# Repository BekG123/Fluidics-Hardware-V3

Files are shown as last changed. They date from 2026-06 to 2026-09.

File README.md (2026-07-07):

Cephla

# Fluidics Controller PCB (V3)

A KiCad hardware design for the fluidics controller used on Cephla/Squid
microscopy systems. It drives the pumps, valves, and sensors that move and
monitor liquid through the instrument, all coordinated by an on-board
Teensy 4.1 microcontroller.

## What it does

The board is the single point of electrical control for the instrument's
liquid path. The Teensy firmware talks to each subsystem over the bus noted
below and exposes a serial interface to the host software.

## Subsystems

| Subsystem | Qty | Interface | Notes |
|---|---|---|---|
| Syringe pump | 1 | RS-232 (`J3`, DB15) | Primary fluid actuation |
| Solenoid valves | up to 7 | GPIO → `U1` TPL7407 → `J5` screw terminal | Low-side driver + per-channel status LEDs |
| Selector valves (IDEX) | 6 | Isolated I²C (5 V) | Addresses set on each valve module |
| Flow sensors | 3 | I²C @ 0x08 | One per I²C port (`J15`/`J17`/`J20`) — fixed address forces separate buses |
| Bubble sensors | 2 | Digital, level-shifted (`J2`/`J4`) | Not I²C |

Isolation and bus conditioning are handled by ADuM1250 / ISO7021 isolators,
a PCA9615 differential-I²C link, and UART/logic level shifters.

## Board specs

- **MCU:** Teensy 4.1 (footprint `U2`, on-board)
- **Stack-up:** 4-layer — `F.Cu` / `In1.Cu` (GND) / `In2.Cu` (+24 V & +5 V planes) / `B.Cu`
- **Power:** +24 V input; Pololu DC-DC regulators for +5 V; on-board LDO (`U3`) for +3.3 V
- **Mounting:** 4 corner plated holes (`H1`–`H4`), chassis GND

## Fabrication

The ready-to-order package lives in `fabrication/v3/`

## Attribution

Derived from `Fluidics-Hardware-V2` by Kevin Marx. V3 modifications by
Bekhruz Malikov (<bekhruz.malikov@cephla.com>). Built with KiCad 10.

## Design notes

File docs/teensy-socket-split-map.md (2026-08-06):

# Teensy socket split (Route B) — pin/net map

Generated from `fluidics-v3/fluidics-v2.kicad_pcb`. U2 origin **(178.23, 51.33)**, rotation 0.

## Parts

| Part | Covers | Footprint | PCB position | PCB rotation |
|---|---|---|---|---|
| **J6** (left socket) | old U2 pins **1–24** | `teensy4.1:PinSocket_1x24_P2.54mm_Vertical_SMD_DualLand` | 170.61, 51.33 | 0° |
| **J7** (right socket) | old U2 pins **25–48** | same footprint | 185.85, 51.33 | 180° |

Both sockets are the same part (Harwin M20-786 series, 1×24 SMT). J7 is J6 rotated 180°, which is why J7 pin *n* lands on old U2 pin *n+24*. Schematic rotation is irrelevant — only the **PCB** rotation above matters.

> Note: auto-annotation reused the designators **J6/J7**, which belonged to the 1×02 terminal blocks removed in commit `5ce1d61`. Renaming them to J26/J27 avoids confusion when comparing against older fab packages, but is optional.

## How to connect (summary)

| Method | Count | Pins (U2 numbering) |
|---|---:|---|
| Label | 34 | 4, 5, 6, 7, 8, 9, 10, 11, 12, 13, 14, 16, 17, 24, 25, 26, 27, 28, 29, 30, 31, 32, 33, 35, 36, 37, 38, 39, 40, 41, 42, 43, 44, 45 |
| **GND power symbol** | 3 | 1, 34, 47 |
| **No-connect flag** | 4 | 2, 3, 15, 46 |
| **Label both ends** | 7 | 18, 19, 20, 21, 22, 23, 48 |

Label text **never includes the leading `/`** — that is the sheet path, not part of the name. `~{...}` is overbar markup and must be typed exactly as shown.

## Full map

| U2 pin | Teensy function | Current net | Socket | Socket pin | Label text to place | Method |
|---:|---|---|---|---:|---|---|
| 1 | GND_1 | `GND` | J6 | 1 | `GND` | **GND power symbol** |
| 2 | 0_RX1_CRX2_CS1_2 | *(auto)* | J6 | 2 | — | **No-connect flag** |
| 3 | 1_TX1_CTX2_MISO1_3 | *(auto)* | J6 | 3 | — | **No-connect flag** |
| 4 | 2_OUT2_4 | `/VALVES_~{RST}` | J6 | 4 | `VALVES_~{RST}` | Label |
| 5 | 3_LRCLK2_5 | `/VALVES_PWM` | J6 | 5 | `VALVES_PWM` | Label |
| 6 | 4_BCLK2_6 | `/GPIO_9` | J6 | 6 | `GPIO_9` | Label |
| 7 | 5_IN2_7 | `/GPIO_8` | J6 | 7 | `GPIO_8` | Label |
| 8 | 6_OUT1D_8 | `/~{INVALID}_SYRPUMP` | J6 | 8 | `~{INVALID}_SYRPUMP` | Label |
| 9 | 7_RX2_OUT1A_9 | `/UART_TX_SYRPUMP` | J6 | 9 | `UART_TX_SYRPUMP` | Label |
| 10 | 8_TX2_IN1_10 | `/UART_RX_SYRPUMP` | J6 | 10 | `UART_RX_SYRPUMP` | Label |
| 11 | 9_OUT1C_11 | `/SPI_~{CS}_PRESS` | J6 | 11 | `SPI_~{CS}_PRESS` | Label |
| 12 | 10_CS_MQSR_12 | `/SPI_~{CS}_VALVES` | J6 | 12 | `SPI_~{CS}_VALVES` | Label |
| 13 | 11_MOSI_CTX1_13 | `/SPI_MOSI` | J6 | 13 | `SPI_MOSI` | Label |
| 14 | 12_MISO_MQSL_14 | `/SPI_MISO` | J6 | 14 | `SPI_MISO` | Label |
| 15 | 3V3_15 | *(auto)* | J6 | 15 | — | **No-connect flag** |
| 16 | 24_A10_TX6_SCL2_16 | `/SCL2` | J6 | 16 | `SCL2` | Label |
| 17 | 25_A11_RX6_SDA2_17 | `/SDA2` | J6 | 17 | `SDA2` | Label |
| 18 | 26_A12_MOSI1_18 | `/Bubble Sensors/2B 3.3V` | J6 | 18 | `BUB_2B` | **Label both ends** |
| 19 | 27_A13_SCK1_19 | `/Bubble Sensors/2A 3.3V` | J6 | 19 | `BUB_2A` | **Label both ends** |
| 20 | 28_RX7_20 | `/Bubble Sensors/1B 3.3V` | J6 | 20 | `BUB_1B` | **Label both ends** |
| 21 | 29_TX7_21 | `/Bubble Sensors/1A 3.3V` | J6 | 21 | `BUB_1A` | **Label both ends** |
| 22 | 30_CRX3_22 | `/Bubble Sensors/Calib 2 3.3V` | J6 | 22 | `BUB_CALIB2` | **Label both ends** |
| 23 | 31_CTX3_23 | `/Bubble Sensors/Calib 1 3.3V` | J6 | 23 | `BUB_CALIB1` | **Label both ends** |
| 24 | 32_OUT1B_24 | `/PG-12V` | J6 | 24 | `PG-12V` | Label |
| 25 | 33_MCLK2_25 | `/PG-5V` | J7 | 1 | `PG-5V` | Label |
| 26 | 34_RX8_26 | `/~{CS}3` | J7 | 2 | `~{CS}3` | Label |
| 27 | 35_TX8_27 | `/~{CS}2` | J7 | 3 | `~{CS}2` | Label |
| 28 | 36_CS_28 | `/~{CS}1` | J7 | 4 | `~{CS}1` | Label |
| 29 | 37_CS_29 | `/~{CS}0` | J7 | 5 | `~{CS}0` | Label |
| 30 | 38_CS1_IN1_30 | `/GPIO_7` | J7 | 6 | `GPIO_7` | Label |
| 31 | 39_MISO1_OUT1A_31 | `/GPIO_6` | J7 | 7 | `GPIO_6` | Label |
| 32 | 40_A16_32 | `/GPIO_5` | J7 | 8 | `GPIO_5` | Label |
| 33 | 41_A17_33 | `/POT_ANALOG` | J7 | 9 | `POT_ANALOG` | Label |
| 34 | GND_34 | `GND` | J7 | 10 | `GND` | **GND power symbol** |
| 35 | 13_SCK_LED_35 | `/SPI_SCK` | J7 | 11 | `SPI_SCK` | Label |
| 36 | 14_A0_TX3_SPDIF_OUT_36 | `/UART_RX_DISCPUMP` | J7 | 12 | `UART_RX_DISCPUMP` | Label |
| 37 | 15_A1_RX3_SPDIF_IN_37 | `/UART_TX_DISCPUMP` | J7 | 13 | `UART_TX_DISCPUMP` | Label |
| 38 | 16_A2_RX4_SCL1_38 | `/SCL1` | J7 | 14 | `SCL1` | Label |
| 39 | 17_A3_TX4_SDA1_39 | `/SDA1` | J7 | 15 | `SDA1` | Label |
| 40 | 18_A4_SDA_40 | `/SCL` | J7 | 16 | `SCL` | Label |
| 41 | 19_A5_SCL_41 | `/SDA` | J7 | 17 | `SDA` | Label |
| 42 | 20_A6_TX5_LRCLK1_42 | `/GPIO_4` | J7 | 18 | `GPIO_4` | Label |
| 43 | 21_A7_RX5_BCLK1_43 | `/GPIO_3` | J7 | 19 | `GPIO_3` | Label |
| 44 | 22_A8_CTX1_44 | `/GPIO_2` | J7 | 20 | `GPIO_2` | Label |
| 45 | 23_A9_CRX1_MCLK1_45 | `/GPIO_1` | J7 | 21 | `GPIO_1` | Label |
| 46 | 3V3_46 | *(auto)* | J7 | 22 | — | **No-connect flag** |
| 47 | GND_47 | `GND` | J7 | 23 | `GND` | **GND power symbol** |
| 48 | VIN_48 | `Net-(D21-K)` | J7 | 24 | `VIN` | **Label both ends** |

## The 7 pins that need care

- **U2.18** (26_A12_MOSI1_18) — `/Bubble Sensors/2B 3.3V`: named inside the *Bubble Sensors* subsheet; label the root-sheet wire too. Put `BUB_2B` on the existing U2 pin wire **and** on J6.18. This renames the net to `/BUB_2B` in the PCB (cosmetic).
- **U2.19** (27_A13_SCK1_19) — `/Bubble Sensors/2A 3.3V`: named inside the *Bubble Sensors* subsheet; label the root-sheet wire too. Put `BUB_2A` on the existing U2 pin wire **and** on J6.19. This renames the net to `/BUB_2A` in the PCB (cosmetic).
- **U2.20** (28_RX7_20) — `/Bubble Sensors/1B 3.3V`: named inside the *Bubble Sensors* subsheet; label the root-sheet wire too. Put `BUB_1B` on the existing U2 pin wire **and** on J6.20. This renames the net to `/BUB_1B` in the PCB (cosmetic).
- **U2.21** (29_TX7_21) — `/Bubble Sensors/1A 3.3V`: named inside the *Bubble Sensors* subsheet; label the root-sheet wire too. Put `BUB_1A` on the existing U2 pin wire **and** on J6.21. This renames the net to `/BUB_1A` in the PCB (cosmetic).
- **U2.22** (30_CRX3_22) — `/Bubble Sensors/Calib 2 3.3V`: named inside the *Bubble Sensors* subsheet; label the root-sheet wire too. Put `BUB_CALIB2` on the existing U2 pin wire **and** on J6.22. This renames the net to `/BUB_CALIB2` in the PCB (cosmetic).
- **U2.23** (31_CTX3_23) — `/Bubble Sensors/Calib 1 3.3V`: named inside the *Bubble Sensors* subsheet; label the root-sheet wire too. Put `BUB_CALIB1` on the existing U2 pin wire **and** on J6.23. This renames the net to `/BUB_CALIB1` in the PCB (cosmetic).
- **U2.48** (VIN_48) — `Net-(D21-K)`: net is unnamed today; label U2.48 *and* the socket pin. Put `VIN` on the existing U2 pin wire **and** on J7.24. This renames the net to `/VIN` in the PCB (cosmetic).

## Verification

After Update PCB and a zone refill, DRC must match the current baseline: **6 unconnected** (5 intentional GPIO_8/9 + SPI no-connects, 1 pre-existing +5V stub gap near U13/U4), 0 shorts / clearance / isolated copper / starved thermals. A higher count means a mismapped pin.

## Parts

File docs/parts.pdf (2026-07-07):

JLCPCB PCBA Viewer | https://cart.jlcpcb.com/smt-order/?pcbFileNo=f7d9450...

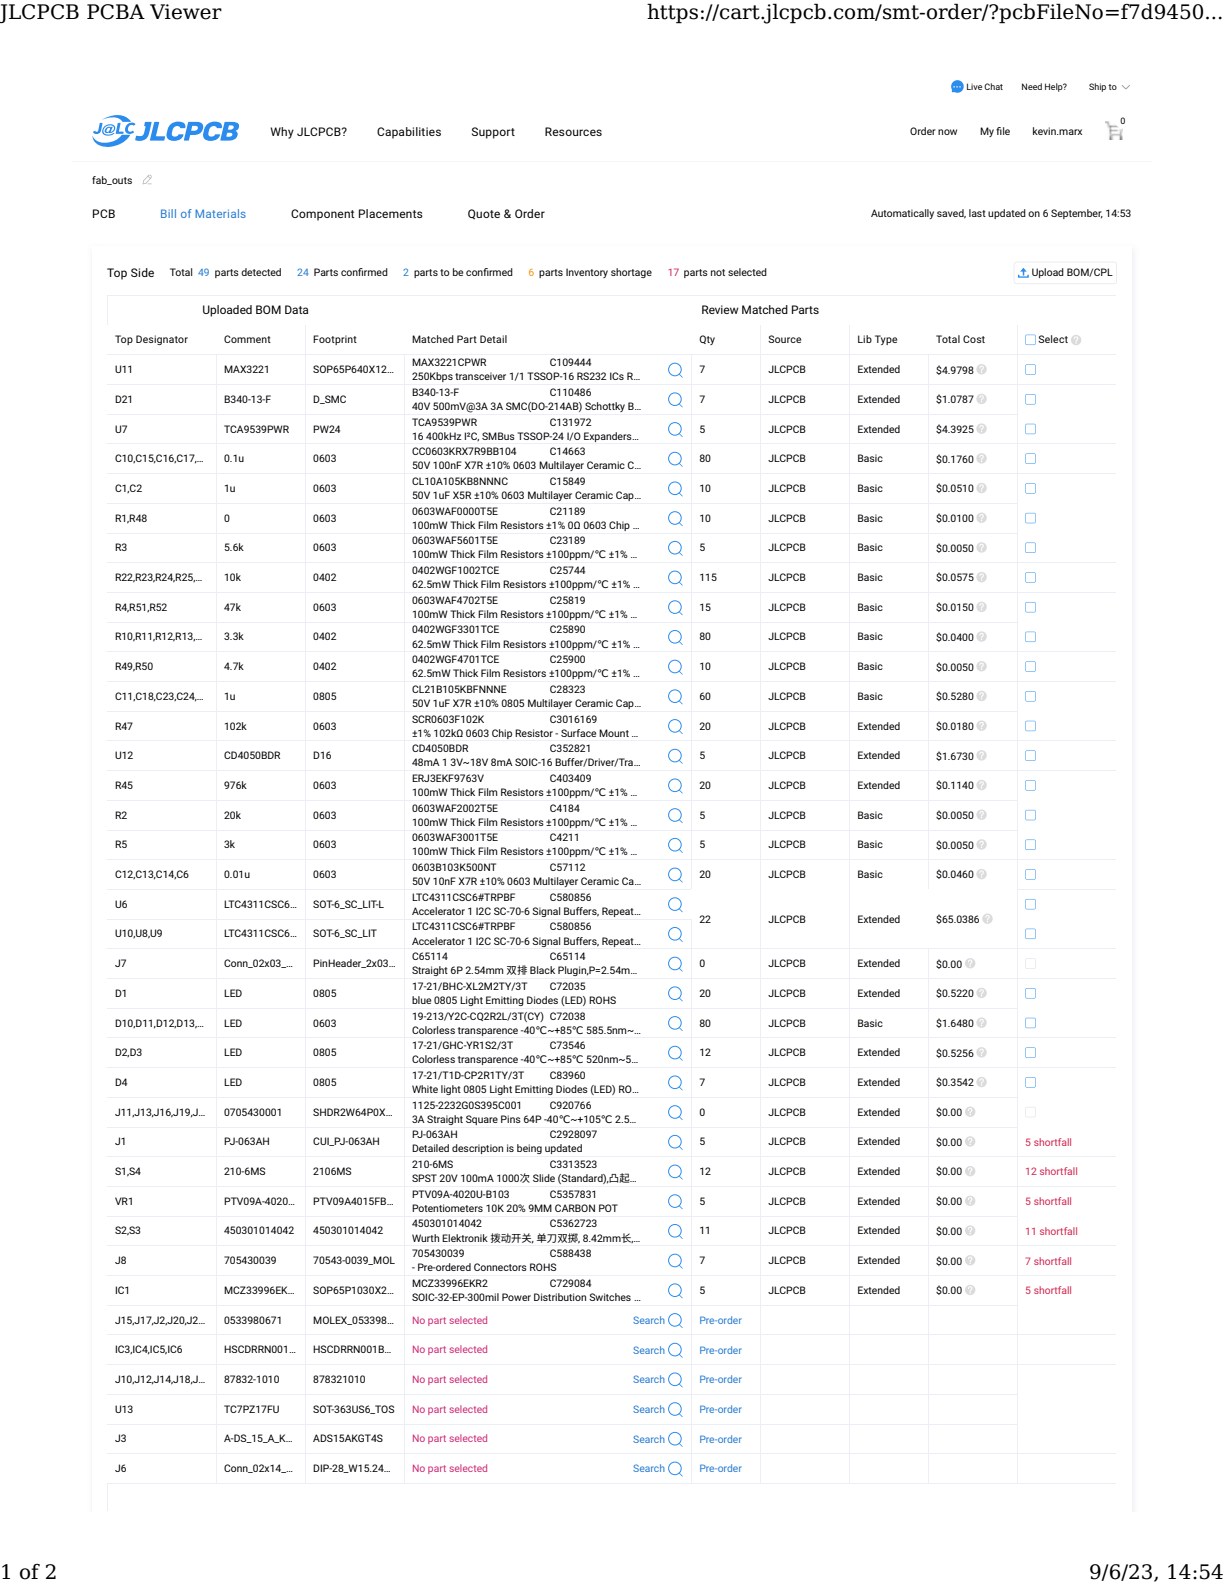
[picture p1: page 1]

Automatically saved, last updated on 6 September, 14:53

Uploaded BOM Data | Review Matched Parts

Top Designator | Comment | Footprint | Matched Part Detail | Qty | Source | Lib Type | Total Cost | Select

U11 | MAX3221 | SOP65P640X12… | MAX3221CPWR C109444 250Kbps transceiver 1/1 TSSOP-16 RS232 ICs R… | 7 | JLCPCB | Extended | $4.9798

D21 | B340-13-F | D_SMC | B340-13-F C110486 40V 500mV@3A 3A SMC(DO-214AB) Schottky B… | 7 | JLCPCB | Extended | $1.0787

U7 | TCA9539PWR | PW24 | TCA9539PWR C131972 16 400kHz I²C, SMBus TSSOP-24 I/O Expanders… | 5 | JLCPCB | Extended | $4.3925

C10,C15,C16,C17,… | 0.1u | 0603 | CC0603KRX7R9BB104 C14663 50V 100nF X7R ±10% 0603 Multilayer Ceramic C… | 80 | JLCPCB | Basic | $0.1760

C1,C2 | 1u | 0603 | CL10A105KB8NNNC C15849 50V 1uF X5R ±10% 0603 Multilayer Ceramic Cap… | 10 | JLCPCB | Basic | $0.0510

R1,R48 | 0 | 0603 | 0603WAF0000T5E C21189 100mW Thick Film Resistors ±1% 0Ω 0603 Chip … | 10 | JLCPCB | Basic | $0.0100

R3 | 5.6k | 0603 | 0603WAF5601T5E C23189 100mW Thick Film Resistors ±100ppm/℃ ±1% … | 5 | JLCPCB | Basic | $0.0050

R22,R23,R24,R25,… | 10k | 0402 | 0402WGF1002TCE C25744 62.5mW Thick Film Resistors ±100ppm/℃ ±1% … | 115 | JLCPCB | Basic | $0.0575

R4,R51,R52 | 47k | 0603 | 0603WAF4702T5E C25819 100mW Thick Film Resistors ±100ppm/℃ ±1% … | 15 | JLCPCB | Basic | $0.0150

R10,R11,R12,R13,… | 3.3k | 0402 | 0402WGF3301TCE C25890 62.5mW Thick Film Resistors ±100ppm/℃ ±1% … | 80 | JLCPCB | Basic | $0.0400

R49,R50 | 4.7k | 0402 | 0402WGF4701TCE C25900 62.5mW Thick Film Resistors ±100ppm/℃ ±1% … | 10 | JLCPCB | Basic | $0.0050

C11,C18,C23,C24,… | 1u | 0805 | CL21B105KBFNNNE C28323 50V 1uF X7R ±10% 0805 Multilayer Ceramic Cap… | 60 | JLCPCB | Basic | $0.5280

R47 | 102k | 0603 | SCR0603F102K C3016169 ±1% 102kΩ 0603 Chip Resistor - Surface Mount … | 20 | JLCPCB | Extended | $0.0180

U12 | CD4050BDR | D16 | CD4050BDR C352821 48mA 1 3V~18V 8mA SOIC-16 Buffer/Driver/Tra… | 5 | JLCPCB | Extended | $1.6730

R45 | 976k | 0603 | ERJ3EKF9763V C403409 100mW Thick Film Resistors ±100ppm/℃ ±1% … | 20 | JLCPCB | Extended | $0.1140

R2 | 20k | 0603 | 0603WAF2002T5E C4184 100mW Thick Film Resistors ±100ppm/℃ ±1% … | 5 | JLCPCB | Basic | $0.0050

R5 | 3k | 0603 | 0603WAF3001T5E C4211 100mW Thick Film Resistors ±100ppm/℃ ±1% … | 5 | JLCPCB | Basic | $0.0050

C12,C13,C14,C6 | 0.01u | 0603 | 0603B103K500NT C57112 50V 10nF X7R ±10% 0603 Multilayer Ceramic Ca… | 20 | JLCPCB | Basic | $0.0460

U6 | LTC4311CSC6… | SOT-6_SC_LIT-L | LTC4311CSC6#TRPBF C580856 Accelerator 1 I2C SC-70-6 Signal Buffers, Repeat… | 22 | JLCPCB | Extended | $65.0386

U10,U8,U9 | LTC4311CSC6… | SOT-6_SC_LIT | LTC4311CSC6#TRPBF C580856 Accelerator 1 I2C SC-70-6 Signal Buffers, Repeat…

J7 | Conn_02x03_… | PinHeader_2x03… | C65114 C65114 Straight 6P 2.54mm 双排 Black Plugin,P=2.54m… | 0 | JLCPCB | Extended | $0.00

D1 | LED | 0805 | 17-21/BHC-XL2M2TY/3T C72035 blue 0805 Light Emitting Diodes (LED) ROHS | 20 | JLCPCB | Extended | $0.5220

D10,D11,D12,D13,… | LED | 0603 | 19-213/Y2C-CQ2R2L/3T(CY) C72038 Colorless transparence -40℃~+85℃ 585.5nm~… | 80 | JLCPCB | Basic | $1.6480

D2,D3 | LED | 0805 | 17-21/GHC-YR1S2/3T C73546 Colorless transparence -40℃~+85℃ 520nm~5… | 12 | JLCPCB | Extended | $0.5256

D4 | LED | 0805 | 17-21/T1D-CP2R1TY/3T C83960 White light 0805 Light Emitting Diodes (LED) RO… | 7 | JLCPCB | Extended | $0.3542

J11,J13,J16,J19,J… | 0705430001 | SHDR2W64P0X… | 1125-2232G0S395C001 C920766 3A Straight Square Pins 64P -40℃~+105℃ 2.5… | 0 | JLCPCB | Extended | $0.00

J1 | PJ-063AH | CUI_PJ-063AH | PJ-063AH C2928097 Detailed description is being updated | 5 | JLCPCB | Extended | $0.00 | 5 shortfall

S1,S4 | 210-6MS | 2106MS | 210-6MS C3313523 SPST 20V 100mA 1000次 Slide (Standard),凸起… | 12 | JLCPCB | Extended | $0.00 | 12 shortfall

VR1 | PTV09A-4020… | PTV09A4015FB… | PTV09A-4020U-B103 C5357831 Potentiometers 10K 20% 9MM CARBON POT | 5 | JLCPCB | Extended | $0.00 | 5 shortfall

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

JLCPCB PCBA Viewer | https://cart.jlcpcb.com/smt-order/?pcbFileNo=f7d9450...

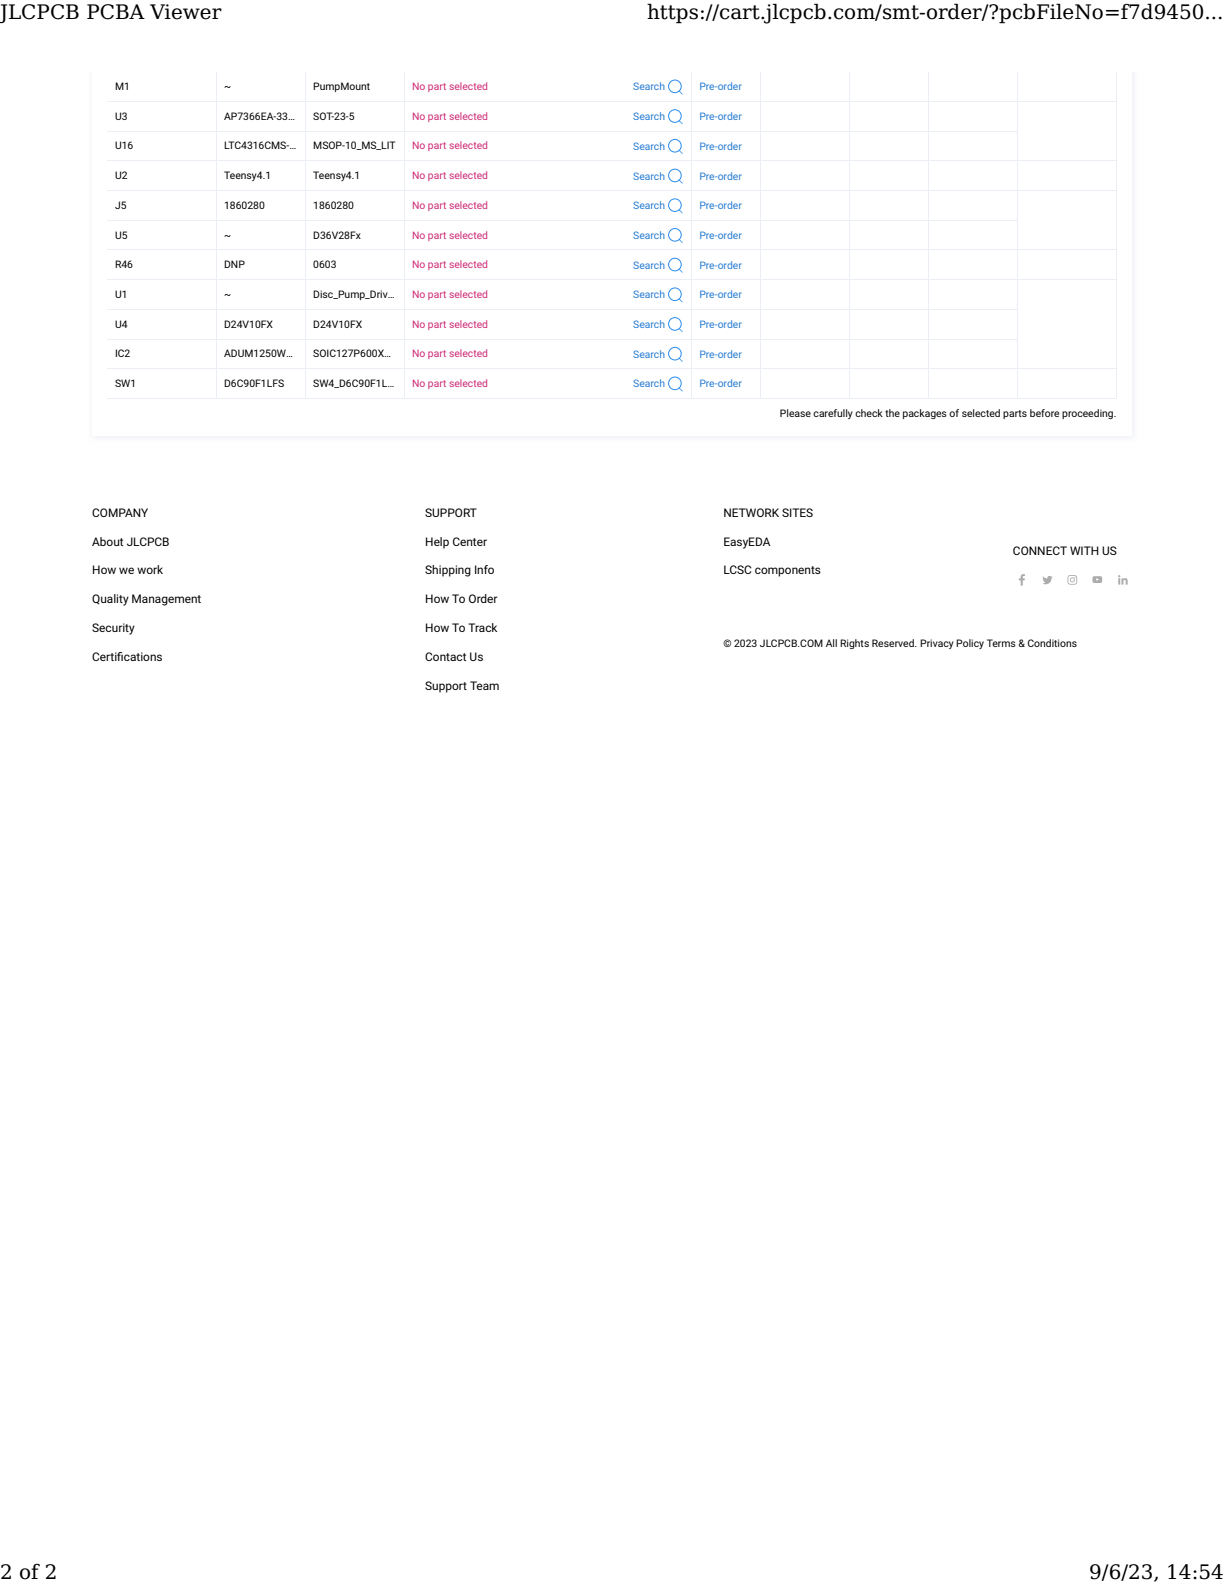
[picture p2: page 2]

U3 | AP7366EA-33… | SOT-23-5 | No part selected Search | Pre-order (https://jlcpcb.com/user-center/smtPrivateLibrary/?index=1)

U16 | LTC4316CMS-… | MSOP-10_MS_LIT | No part selected Search | Pre-order (https://jlcpcb.com/user-center/smtPrivateLibrary/?index=1)

U2 | Teensy4.1 | Teensy4.1 | No part selected Search | Pre-order (https://jlcpcb.com/user-center/smtPrivateLibrary/?index=1)

J5 | 1860280 | 1860280 | No part selected Search | Pre-order (https://jlcpcb.com/user-center/smtPrivateLibrary/?index=1)

U5 | ~ | D36V28Fx | No part selected Search | Pre-order (https://jlcpcb.com/user-center/smtPrivateLibrary/?index=1)

R46 | DNP | 0603 | No part selected Search | Pre-order (https://jlcpcb.com/user-center/smtPrivateLibrary/?index=1)

U1 | ~ | Disc_Pump_Driv… | No part selected Search | Pre-order (https://jlcpcb.com/user-center/smtPrivateLibrary/?index=1)

U4 | D24V10FX | D24V10FX | No part selected Search | Pre-order (https://jlcpcb.com/user-center/smtPrivateLibrary/?index=1)

IC2 | ADUM1250W… | SOIC127P600X… | No part selected Search | Pre-order (https://jlcpcb.com/user-center/smtPrivateLibrary/?index=1)

SW1 | D6C90F1LFS | SW4_D6C90F1L… | No part selected Search | Pre-order (https://jlcpcb.com/user-center/smtPrivateLibrary/?index=1)

Please carefully check the packages of selected parts before proceeding.

© 2023 JLCPCB.COM All Rights Reserved. Privacy Policy (https://jlcpcb.com/help/article/31-Privacy-Policy) Terms & Conditions (https://jlcpcb.com/help/article/30-Terms-&-Conditions)

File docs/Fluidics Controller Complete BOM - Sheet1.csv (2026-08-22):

OFF-BOARD DEVICES AND CONNECTORS
Id | Designator | Quantity Per PCB | Part Number | Value | Footprint | Notes
 | N/A | 1 | SLF3S-0600F | N/A | N/A | Flowrate sensor
 | N/A | 4 | "0151340602" | N/A | N/A | Connect flowrate or other I2C device to J15, J20, J23, J17. Only one necessary if connecting only one off-board I2C device
 | N/A | 2 | OCB350L062Z | N/A | N/A | Bubble sensor
 | N/A | 2 | A06ZR06ZR28H152B | N/A | N/A | Connects bubble sensor to J2, J4
 | N/A | 5 | MLP778-605 | N/A | N/A | IDEX selector valve
 | N/A | 10 | "0511101060" | N/A | N/A | 2 per selector valve, for I2C connection, connects to J21,18,14,12,10
 | N/A | 15 | "0797581095" | N/A | N/A | 3 wires per selector valve, for I2C connection, connects to J21,18,14,12,10
 | N/A | 10 | "050579"0"0402""" | N/A | N/A | 2 per selector valve, for 24V power, connects to J22,19,16,13,11
 | N/A | 10 | "0797580011" | N/A | N/A | 2 wires per selector valve, for 24V power, connects to J22,19,16,13,11
 | N/A | 1 | Kamoer KSY-30 | N/A | N/A | Syringe pump, implementation in progress
 | N/A | 1 | H7SSH-1506M-ND | N/A | N/A | Cable for connecting to syringe pump
 | N/A | 2 | "050579205" | N/A | N/A | Bring power (gnd, 3V3, 5V, 12V, 24V) off board. Connects to J8
 | N/A | 5 | "0797580011" | N/A | N/A | Bring power (gnd, 3V3, 5V, 12V, 24V) off board. Connects to J8
 | N/A | 1 | "0152670366" | N/A | N/A | FPC cable brings GPIO, IO busses off-board. Connects to J9
COMPONENTS ON PCB
Designator | Footprint | Quantity | Value | LCSC Part #
C1, C2 | "0603" | 2 | 1u
C10, C15, C16, C17, C19, C20, C21, C22, C3, C30, C31, C32, C33, C34, C5, C9 | "0603" | 16 | 0.1u
C11, C18, C23, C24, C35, C36, C37, C38, C39, C4, C7, C8 | "0805" | 12 | 1u
C12, C13, C14, C6 | "0603" | 4 | 0.01u
D1 | "0805" | 1 | LED | C72035
D10, D11, D12, D13, D14, D15, D16, D17, D18, D19, D20, D5, D6, D7, D8, D9 | "0603" | 16 | LED | C72038
D2, D3 | "0805" | 2 | LED | C73546
D21 | D_SMC | 1 | B340-13-F
D4 | "0805" | 1 | LED | C83960
IC1 | SOP65P1030X265-33N | 1 | MCZ33996EKR2
IC2 | SOIC127P600X175-8N | 1 | ADUM1250WSRZ-RL7
IC3, IC4, IC5, IC6 | HSCDRRN001BDSA3 | 4 | HSCDRRN001BDSA3
J1 | CUI_PJ-063AH | 1 | PJ-063AH | C2928097
J10, J12, J14, J18, J21 | 878321010 | 5 | 87832-1010
J11, J13 | SHDR2W64P0X254_1X2_737X660X1181P | 2 | 705430001 | C5349069
J15, J17, J20, J23 | MOLEX_0533980671 | 4 | 533980671
J16, J19, J22 | SHDR2W64P0X254_1X2_737X660X1181P | 3 | 705430001
J2, J4 | CONN_B6B-ZR-SM4-TF_JST | 2 | B6B-ZR-SM4-TF
J3 | ADS15AKGT4S | 1 | A-DS_15_A_KG-T4S | C3100941
J5 | 1860280 | 1 | 1860280
J6 | DIP-28_W15.24mm_Socket | 1 | Conn_02x14_Counter_Clockwise
J7 | PinHeader_2x03_P2.54mm_Vertical | 1 | Conn_02x03_Odd_Even
J8 | 70543-0039_MOL | 1 | 705430039 | C588438
J9 | CON_522712079_MOL | 1 | 522712079 | C588186
R1, R48 | "0603" | 2 | 0
R10, R11, R12, R13, R14, R15, R16, R17, R18, R19, R20, R21, R6, R7, R8, R9 | "0402" | 16 | 3.3k
R2 | "0603" | 1 | 20k
R22, R23, R24, R25, R26, R27, R28, R29, R30, R31, R32, R33, R34, R35, R36, R37, R38, R39, R40, R41, R42, R43, R44 | "0402" | 23 | 10k
R3 | "0603" | 1 | 5.6k
R4, R51, R52 | "0603" | 3 | 47k
R45 | "0603" | 1 | 976k
R46 | "0603" | 1 | DNP
R47 | "0603" | 1 | 102k
R49, R50, R53, R54, R55, R56, R57, R58, R59 | "0402" | 9 | 4.7k
R5 | "0603" | 1 | 3k
S1, S4 | 2106MS | 2 | 210-6MS
S2, S3 | 450301014042 | 2 | 450301014042
SW1 | SW4_D6C90F1LFS_CNK | 1 | D6C90F1LFS
U10, U8, U9 | SOT-6_SC_LIT | 3 | LTC4311CSC6-TRPBF
U11 | SOP65P640X120-16N | 1 | MAX3221
U12 | D16 | 1 | CD4050BDR
U13 | SOT-363 US6_TOS | 1 | TC7PZ17FU
U16 | MSOP-10_MS_LIT | 1 | LTC4316CMS-TRPBF
U3 | SOT-23-5 | 1 | AP2112K-3.3TRG1
U4 | D24V10FX | 1 | D24V10FX
U5 | D36V28Fx | 1 | ~
U6 | SOT-6_SC_LIT-L | 1 | LTC4311CSC6-TRPBF
U7 | PW24 | 1 | TCA9539PWR
VR1 | PTV09A4015FB103 | 1 | PTV09A-"0402"0U-B103
U2 | N/A | 1 | DEV-16996
U2a, U2b | SSM-124-L-SV | 2 | SSM-124-L-SV
U1 | N/A | 1 | UEKA0300000A
U1a | M50-3030542 | 1 | M50-3030542
U1b | M50-3030442 | 1 | M50-3030442
U1c | M50-3031042 | 1 | M50-3031042
M1 | N/A | 1 | UBLB5401200A
M1a, M1b | 9774050243R | 2 | 9774050243R

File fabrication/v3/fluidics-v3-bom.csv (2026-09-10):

Designator | Value | Footprint | MPN | Manufacturer | LCSC | Qty | DNP
C1,C2 | 1u | Capacitor_SMD:C_0603_1608Metric | CL10A105KB8NNNC | Samsung Electro-Mechanics | C15849 | 2
C3 | 33u 50V | Capacitor_Tantalum_SMD:CP_EIA-7343-20_Kemet-V | T521X336M050ATE050 | KEMET | C2158776 | 1
C4 | 47u | Capacitor_SMD:C_1206_3216Metric | CL31A476MPHNNNE | Samsung Electro-Mechanics | C96123 | 1
C5,C9,C11,C13,C15,C16,C17,C19,C20,C21,C22,C25 | 0.1u | Capacitor_SMD:C_0603_1608Metric | CC0603KRX7R9BB104 | YAGEO | C14663 | 12
C7,C8,C18,C23,C24 | 1u | Capacitor_SMD:C_0805_2012Metric | CL21B105KBFNNNE | Samsung Electro-Mechanics | C28323 | 5
C10 | 100u | Capacitor_SMD:C_1210_3225Metric | EMK325ABJ107MM-T | Taiyo Yuden | C394395 | 1
C12 | 470u 50V | Capacitor_THT:CP_Radial_D10.0mm_P5.00mm | KM1H471MG200A00CV016 | Changzhou Huawei Elec | C2912407 | 1
D2,D3 | LED | LED_SMD:LED_0805_2012Metric | LTST-C170TGKT | Lite-On | C364562 | 2
D4 | LED | LED_SMD:LED_0805_2012Metric | KT-0805R | Hubei KENTO Elec | C2295 | 1
D9,D10,D11,D12 | LED | LED_SMD:LED_0402_1005Metric | LTST-C281KGKT | Lite-On | C160479 | 4
D21 | B340-13-F | Diode_SMD:D_SMC | B340-13-F | Diodes Incorporated | C110486 | 1
IC2 | ADUM1250WSRZ-RL7 | analog_devices:SOIC127P600X175-8N | ISO1640BDR | Texas Instruments | C5122339 | 1
J1 | PJ-063AH | barreljack:CUI_PJ-063AH | PJ-063AH | CUI | C22434582 | 1
J2,J4 | B6B-ZR-SM4-TF | B6B-ZR-SM4-TF:CONN_B6B-ZR-SM4-TF_JST | B6B-ZR-SM4-TF(LF)(SN) | JST | C471473 | 2
J3 | A-DS_15_A_KG-T4S | db15:ADS15AKGT4S | DS1037-15MNCKT74-0CC | CONNFLY Elec | C77837 | 1
J5 | Screw_Terminal_01x06 | TerminalBlock:TerminalBlock_Xinya_XY308-2.54-6P_1x06_P2.54mm_Horizontal | XY308-2.54-6P | Ningbo Xinlaiya Elec. | C915915 | 1
J10,J12,J14,J18,J21,J25 | 87832-0410 | molex_connectors:878320410 | 87832-0410 | Molex |  | 6
J11,J13,J16,J19,J22,J24 | 0705430001 | molex_connectors:SHDR2W64P0X254_1X2_737X660X1181P | 705430001 | MOLEX | C127361 | 6
J15,J17,J20 | 0533980671 | molex_connectors:MOLEX_0533980671 | 533980671 | MOLEX | C277393 | 3
Q1 | F60N80 | Package_TO_SOT_THT:TO-220-3_Vertical | IRF540NPBF | Infineon Technologies | C2566 | 1
R2 | 100k | Resistor_SMD:R_0402_1005Metric | 0402WGF1003TCE | UNI-ROYAL(Uniroyal Elec) | C25741 | 1
R3 | 5.6k | Resistor_SMD:R_0805_2012Metric | 0805W8F5601T5E | UNI-ROYAL(Uniroyal Elec) | C4382 | 1
R4 | 47k | Resistor_SMD:R_0402_1005Metric | 0402WGF4702TCE | UNI-ROYAL(Uniroyal Elec) | C25792 | 1
R5 | 3k | Resistor_SMD:R_0402_1005Metric | RC-02K3001FT | FH (Guangdong Fenghua Advanced Tech) | C140159 | 1
R6 | 68k | Resistor_SMD:R_0402_1005Metric | 0402WGF6802TCE | UNI-ROYAL(Uniroyal Elec) | C36871 | 1
R9,R11,R12 | 2.7k | Resistor_SMD:R_0402_1005Metric | 0402WGF2701TCE | UNI-ROYAL(Uniroyal Elec) | C25885 | 3
R10 | 47k | Resistor_SMD:R_0603_1608Metric | 0603WAF4702T5E | UNI-ROYAL(Uniroyal Elec) | C25819 | 1
R22,R23,R39,R40,R41,R42,R43,R44 | 2.2k | Resistor_SMD:R_0402_1005Metric | 0402WGF2201TCE | UNI-ROYAL(Uniroyal Elec) | C25879 | 8
U1 | TPL7407LDR | TPL7407LDR:SOIC127P600X175-16N | TPL7407LDR | Texas Instruments | C139663 | 1
U3 | AP2112K-3.3TRG1 | Package_TO_SOT_SMD:SOT-23-5 | AP2112K-3.3TRG1 | TECH PUBLIC | C23380830 | 1
U4 | TSR1-2450E | Converter_DCDC:Converter_DCDC_TRACO_TSR1-xxxxE_THT | TSR 1-2450E | TRACO POWER | C5346721 | 1
U11 | MAX3221 | MAX232:SOP65P640X120-16N | MAX3221EIPWR | Texas Instruments | C484736 | 1
U12 | CD4050BDR | hexbuf:D16 | CD4050BDR | Texas Instruments | C352821 | 1
U13 | TC7PZ17FU | TC7PZ17FU:SOT-363 US6_TOS | TC7PZ17FU,LJ(CT) | TOSHIBA | C146298 | 1

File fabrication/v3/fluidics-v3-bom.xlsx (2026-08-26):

Comment | Designator | Footprint | Quantity | LCSC Part #
1uF | C1,C2 | C0603 | 2 | C15849
100uF | C3 | TAJE476K035RNJ | 1 | C7233
47uF | C4 | C1206 | 1 | C96123
100nF | C5,C9,C15,C16,C17,C19,C20,C21,C22 | C0603 | 9 | C14663
10nF | C6 | C0603 | 1 | C57112
1uF | C7,C8,C18,C23,C24 | C0805 | 5 | C28323
100uF | C10 | C1210 | 1 | C7432790
LTST-C170TGKT | D2,D3,D4 | 0805 | 3 | C364562
19-213/Y2C-CQ2R2L/3T(CY) | D9,D10,D11,D12 | 0603 | 4 | C72038
B340-13-F | D21 | SMC | 1 | C110486
ADUM1250WSRZ-RL7 | IC2 | SOIC-8_L4.9-W3.9-P1.27-LS6.0-BL | 1 | C13839
PJ-063AH | J1 | DC-IN_PJ-063BH | 1 | C22434582
B6B-ZR-SM4-TF | J2,J4 | CONN-SMD_6P-P1.50_JST_B6B-ZR-SM4-TF-LF-SN | 2 | C471473
D-SUB-DR-15PCG-AB | J3 | DSUB-TH_D-SUB-DR-15PCG-AB | 1 | C19077347
87832-0410 | J10,J12,J14,J18,J21,J25 | 87832-0410 | 6 | C17692888
SSM-124-L-SV | J6,J7 | CONN-SMD_SSM-124-L-SV-P | 2 | C6497165
XY308-2.54-6P | J5 | CONN-TH_XY308-2.54-6P | 1 | C915915
0705430001 | J11,J13,J16,J19,J22,J24 | CONN-TH_705430001 | 6 | C127361
0533980671 | J15,J17,J20 | CONN-SMD_6P-P1.25-V-M_533980671 | 3 | C277393
5.6k | R3 | R0805 | 1 | C4382
47k | R4 | R0402 | 1 | C25792
3K | R5 | R0402 | 1 | C137987
2.7K | R9,R11,R12 | R0402 | 3 | C138017
47k | R10 | R0603 | 1 | C25819
10K | R22,R23,R39,R40,R41,R42,R43,R44 | R0402 | 8 | C25744
10R | TH1 | RES-TH_L8.5-W5.5-P5.00-D0.6-S5.50 | 1 | C9176
TPL7407LDR | U1 | SOIC-16_L9.9-W3.9-P1.27-LS6.0-BL | 1 | C139663
AP2112K-3.3TRG1 | U3 | SOT-23-5_L3.0-W1.6-P0.95-LS2.8-BR | 1 | C51118
LTC4311CSC6-TRPBF | U6 | SC-70-6_L2.1-W1.3-P0.65-LS2.1-BR | 1 | C580856
TSSOP-16_L5.0-W4.4-P0.65-LS6.4-BL | U11 | MAX3221 | 1 | C484736
CD4050BDR | U12 | SOIC-16_L9.9-W3.9-P1.27-LS6.0-BL | 1 | C352821
TC7PZ17FU | U13 | SOT-363-6_L2.0-W1.3-P0.65-LS2.1-BL-1 | 1 | C146298
TSR 1-2450E | U4 | SIP-3 | 1 | C5346721

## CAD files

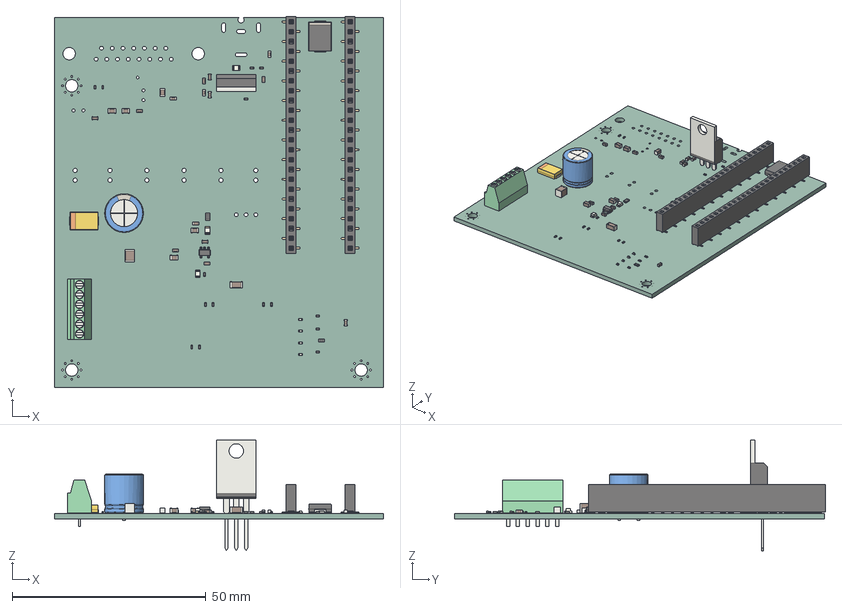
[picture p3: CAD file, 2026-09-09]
fabrication/v3/fluidics-v3.step
85.0 x 95.8 x 28.5 mm
R_0402_1005Metric x 15
R_0603_1608Metric
C_0805_2012Metric x 5
LED_0402_1005Metric x 4
C_0603_1608Metric x 14
R_0805_2012Metric
D_SMC
CP_EIA_7343_20_Kemet_V
TO-220-3_Vertical
C_1206_3216Metric
TerminalBlock_Phoenix_MPT-0,5-6-2.54_1x06_P2.54mm_Horizontal
PinSocket_1x24_P2.54mm_Vertical_SMD_Pin1Left x 2
LED_0805_2012Metric x 3
CP_Radial_D100mm_P500mm
C_1210_3225Metric
SOT-23-5
fluidics-v3_PCB

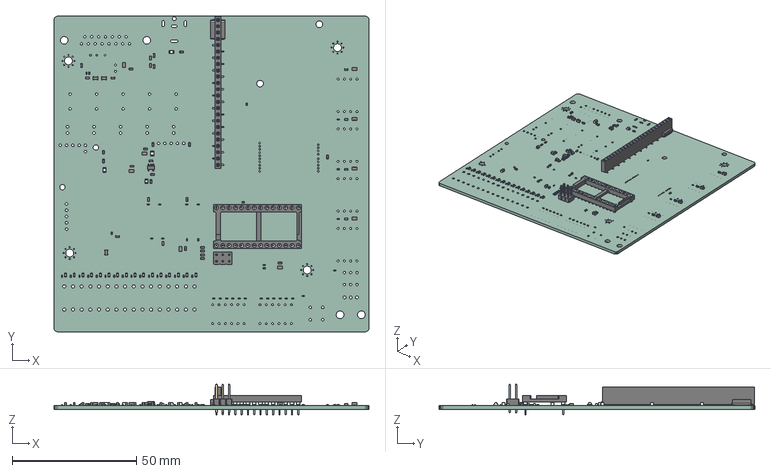
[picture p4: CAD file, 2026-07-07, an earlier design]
fabrication/v2/fluidics-v2.step
127.0 x 127.2 x 12.3 mm
_autosave-fluidics-v2 PCB

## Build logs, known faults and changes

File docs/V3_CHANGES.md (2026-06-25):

# Fluidics Controller — V3 Change Notes

Author: Bekhruz Malikov (<bekhruz.malikov@cephla.com>)
Base: Kevin Marx's `Fluidics-Hardware-V2`
Tooling: KiCad 10 (project migrated from the V2 / KiCad 7 format)

## Summary

V3 strips the V2 fluidics controller down to a minimal build and extends the
selector-valve bank by one channel. Net result: **177 → 86 footprints**, with
**DRC reporting 0 unconnected items**.

## Target configuration

| Subsystem | V2 | V3 | Change |
|---|---|---|---|
| Solenoid valves (on/off, 1× MCZ33996) | 16 | 0 | removed |
| Selector valves (IDEX, isolated I²C) | 5 | 6 | +1 channel |
| Pressure sensors (Honeywell HSC, **SPI**) | 4 | 0 | removed |
| Flow sensors (**I²C**) | 4 | 3 | −1 |
| Bubble sensors | 2 | 2 | unchanged |
| Pumps | disc + syringe | syringe only | disc removed |

## Removed

- **Disc-pump driver** — `U1` (TTP Ventus driver module connector) + `M1`
  (pump mount). The disc pump was UART-controlled; the syringe pump (RS-232)
  is retained.
- **Solenoid-valve subsystem** (whole sheet) — `IC1` (MCZ33996 16-ch low-side
  driver), `D5–D20` (16 flyback indicators), `R6–R21` (16 gate resistors),
  `C3/C4/JP6/R55`, and connector `J5`.
- **All SPI pressure sensors** — `IC3–IC6` (HSCDRRN001BDSA3) and their
  decoupling caps / pull-ups (`C31/C32/C33/C34`, `C36/C37/C38/C39`,
  `R56–R59`).
- **One I²C flow-sensor channel** — connector `J17`.
- **Wenzel-lab pressure-controller daughter board** interface — `J6`
  (SPI/GPIO breakout), `J8` (3.3/5/12/24 V power), `J7` (ICSP) + `JP3`. This
  external module (I²C ADC at 0x48) was paired with the now-removed disc pump.
- **Manual-control block** (whole sheet) — switches `S1–S4`, push-button
  `SW1`, potentiometer `VR1`, GPIO expander `U7` (TCA9539), pull-ups
  `R24–R38`, `C10/C11/JP1/JP2`.
- **24 V → 12 V converter** — `U5` (Pololu D36V28Fx) + 12 V indicator
  `D1/R2` + power-good pull-up `R52`. No 12 V load remained once the
  solenoids and daughter board were removed.

## Added

- **6th IDEX selector-valve channel** — connector pair `J24` (0705430001,
  power: GND / +24 V) and `J25` (87832-1010, signal: SDA 5 V / SCL 5 V / GND),
  tied to the shared **isolated-I²C** bus (ADUM1250 + LTC4311 front-end).
  Placed in the board area freed by the solenoid block; +24 V connects via the
  In2.Cu power plane, GND via the board ground pours. The valve's I²C address
  is set on the IDEX module itself (no on-board addressing hardware).

## Fixed

- **Library path portability** — `fp-lib-table` and `sym-lib-table` referenced
  the original author's hardcoded absolute paths
  (`/home/octopi-codex/Documents/kmarx/...`), which fail on any other machine
  (this blocked adding new footprints). All 140 entries were rewritten to
  `${KIPRJMOD}/../`-relative URIs so the libraries resolve anywhere.
- **`.gitignore`** added for KiCad lock/autosave/cache and editor-history
  files (the V2 repo had several `*.lck` files committed).

## Notes / retained

- The board is 4-layer: F.Cu / In1.Cu (GND) / In2.Cu (+24 V & +5 V planes) /
  B.Cu, with GND poured on the outer layers.
- Mounting holes `H1–H4` (corner, plated, chassis-GND) are unchanged.
- The SPI bus is retained (Teensy + connector `J9`) even though no SPI sensor
  remains; the freed Teensy SPI pins are simply unused.
- `pctrl.kicad_sch` is an orphaned sheet (not instantiated in the design) and
  can be deleted in a follow-up.

## Known TODO

- **Board not yet physically resized.** The outline (Edge.Cuts) is still the
  V2 ~127 mm square — removing parts only freed space, it did not shrink the
  board. A resize requires compacting the remaining parts, redrawing the
  outline, repositioning the mounting holes, and re-pouring the zones, and
  depends on whether the enclosure / mounting-hole pattern is fixed.

## Verification method

Changes were applied in the KiCad GUI (schematic edit → "Update PCB from
Schematic" → cleanup → DRC). After each step the netlist was diffed and DRC
re-run via `kicad-cli` to confirm exactly the intended parts changed and that
connectivity stayed intact. Final state: 86 footprints, 0 unconnected.

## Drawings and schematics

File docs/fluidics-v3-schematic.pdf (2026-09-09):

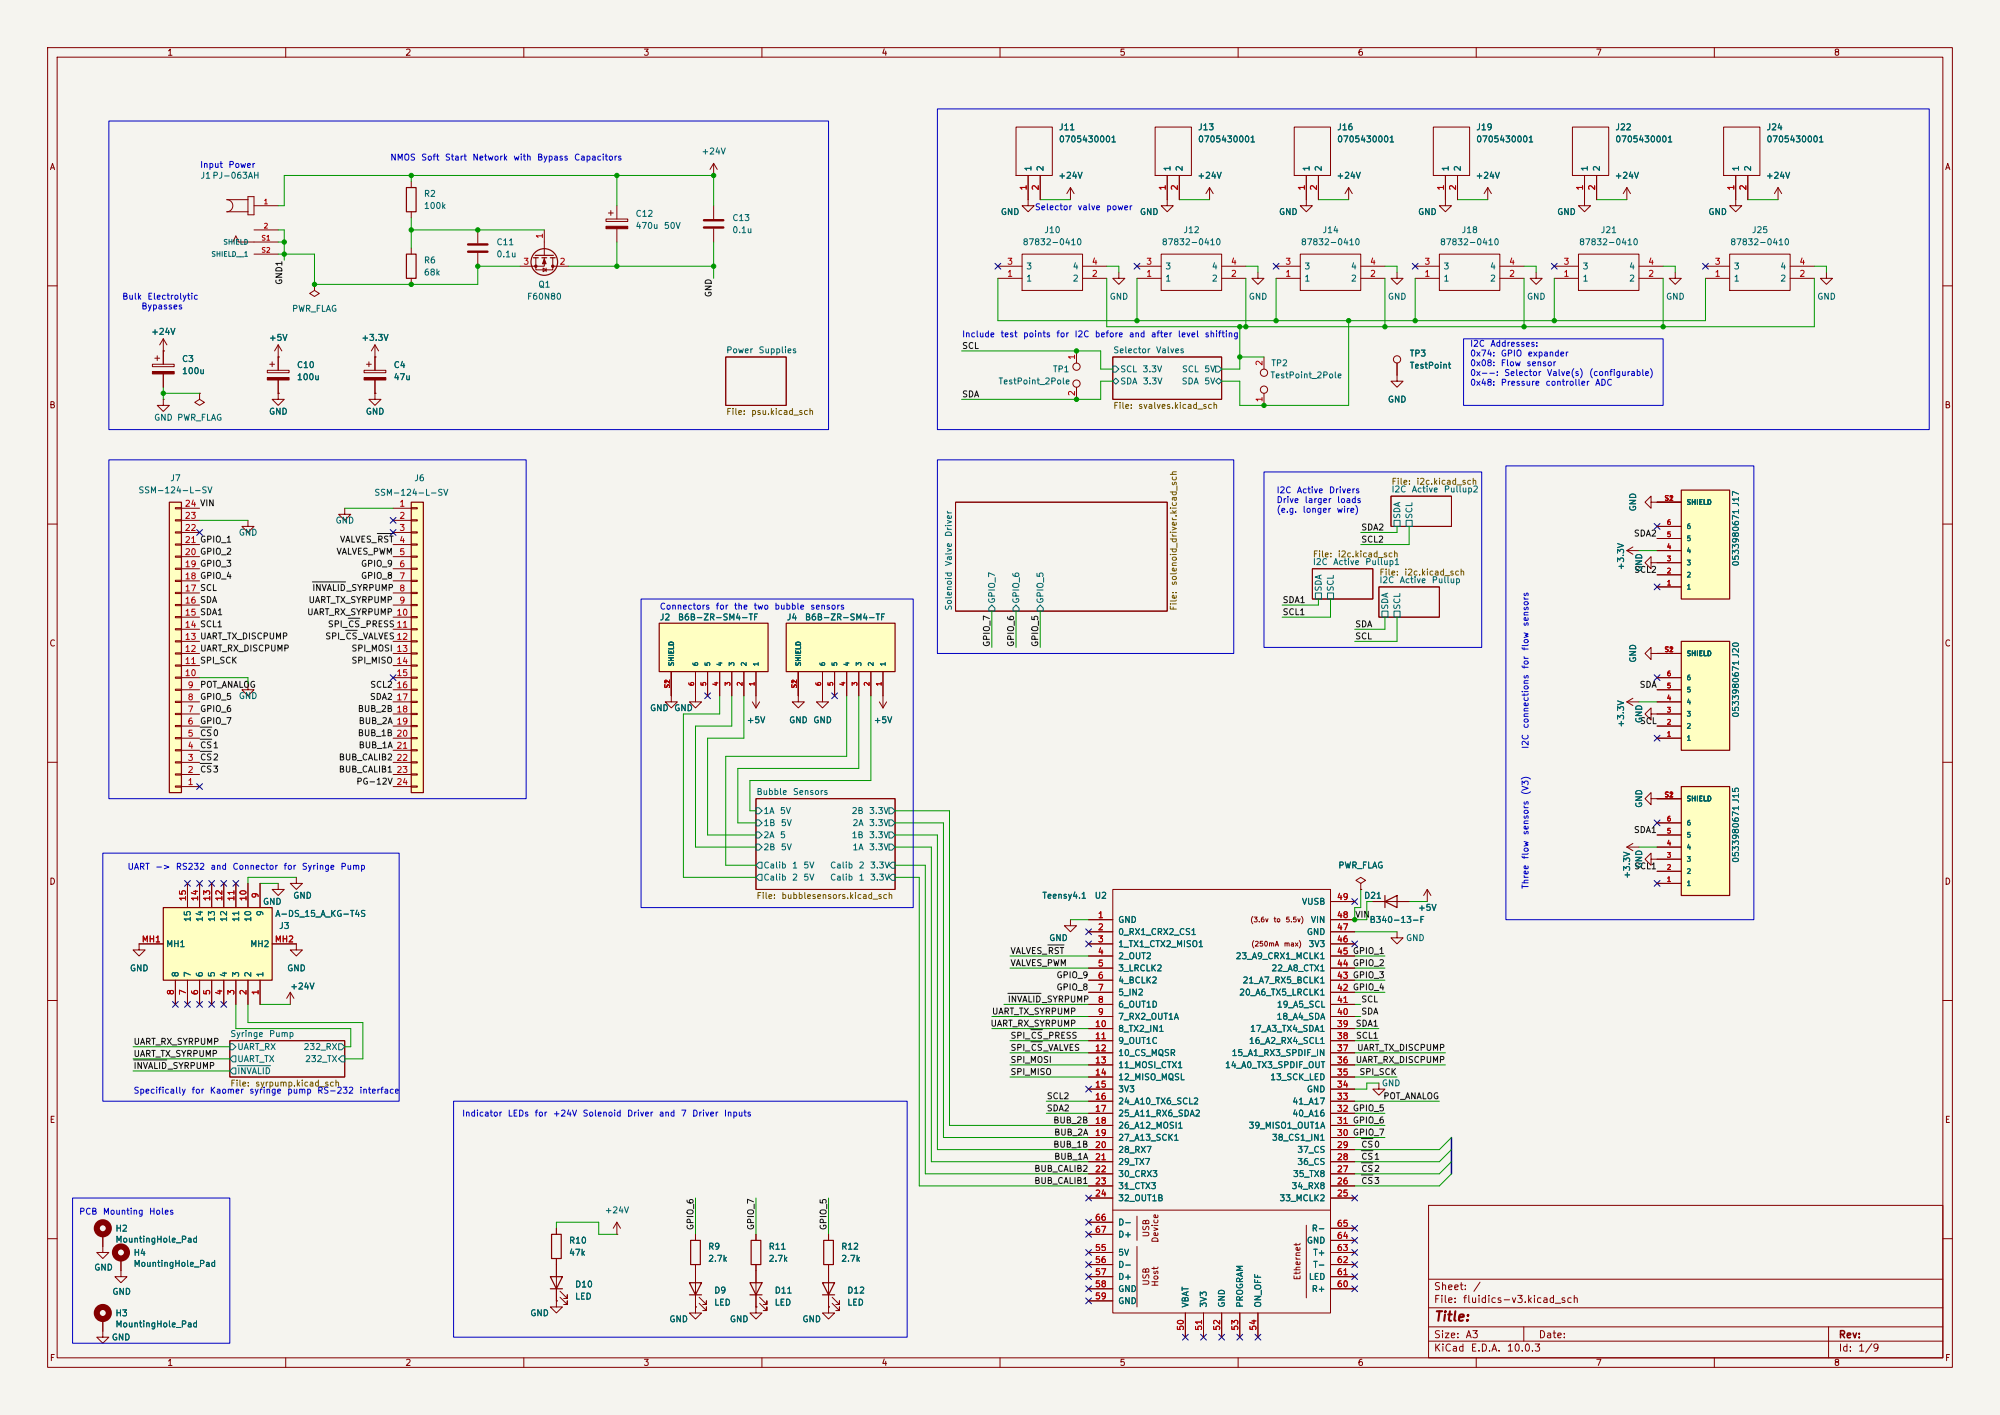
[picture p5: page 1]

NMOS Soft Start Network with Bypass Capacitors

I2C Addresses: 0x74: GPIO expander 0x08: Flow sensor 0x--: Selector Valve(s) (configurable) 0x48: Pressure controller ADC

I2C Active Drivers Drive larger loads
Sheet: / SDA SCL

Connectors for the two bubble sensors

6 SHIELD S12 J4 B6B-ZR-SM4-TF GND

6 SHIELD S12 J2 B6B-ZR-SM4-TF GND

UART -> RS232 and Connector for Syringe Pump

Specifically for Kaomer syringe pump RS-232 interface

Indicator LEDs for +24V Solenoid Driver and 7 Driver Inputs

PCB Mounting Holes H4MountingHole_Pad GND
GND H3MountingHole_Pad H2MountingHole_Pad GND

Size: A3 | Rev: | F Date:
KiCad E.D.A. 10.0.3 | Id: 1/9

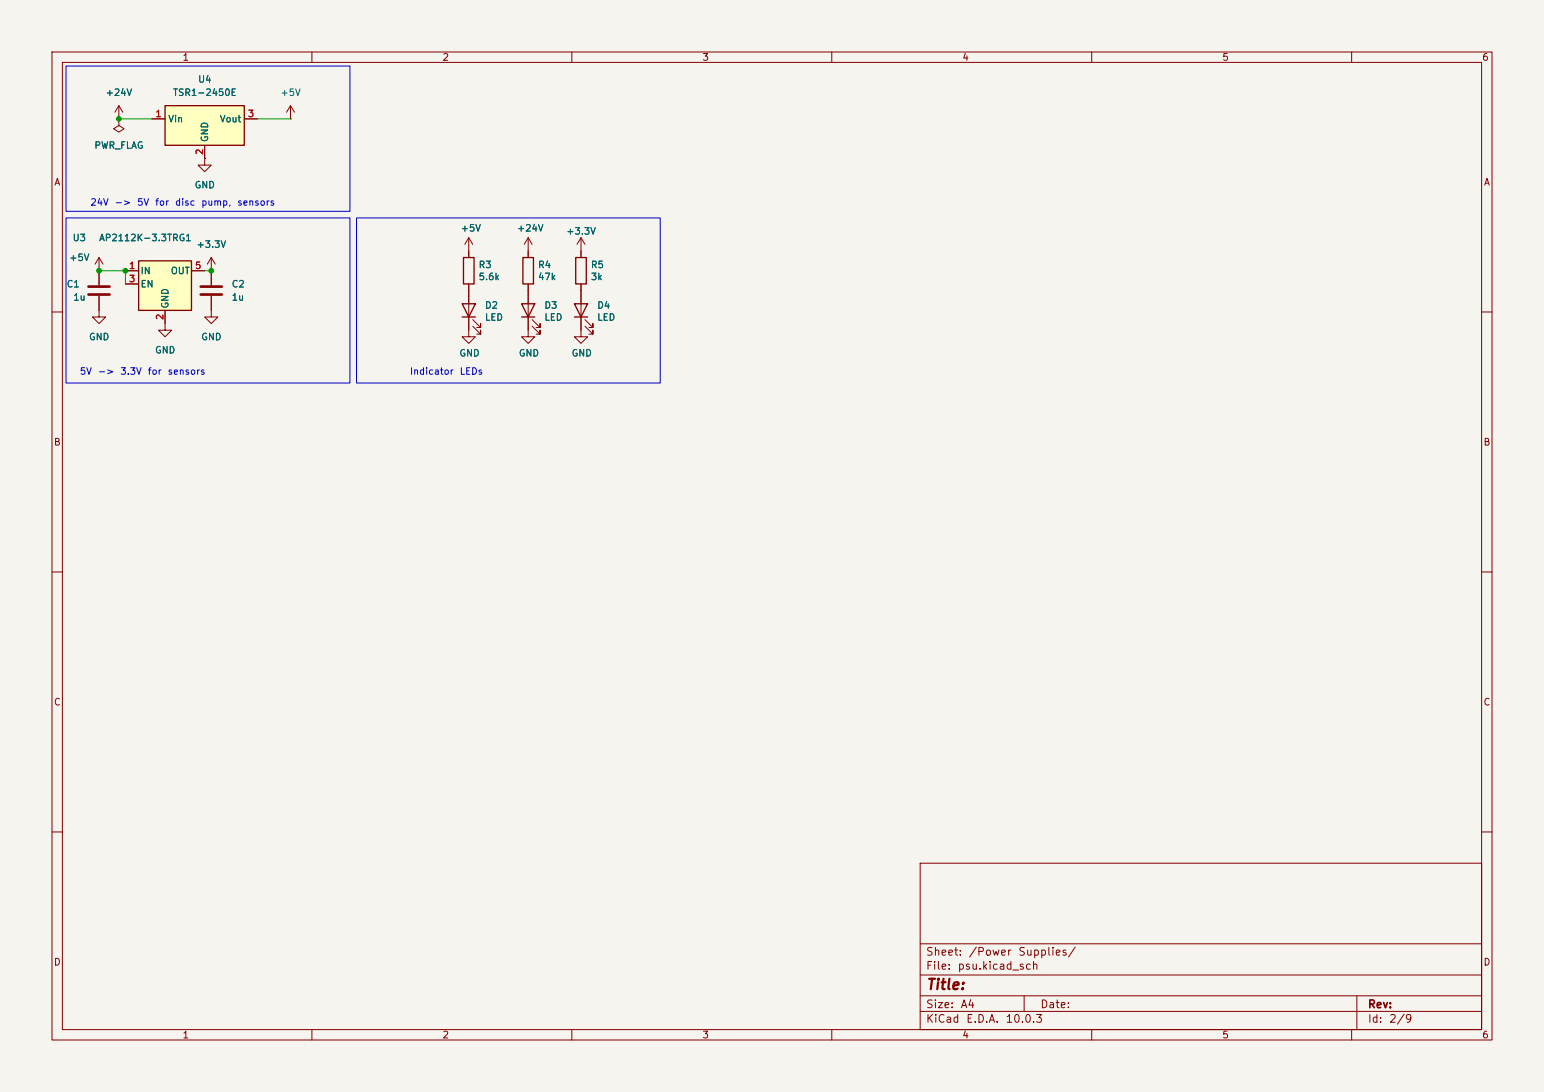
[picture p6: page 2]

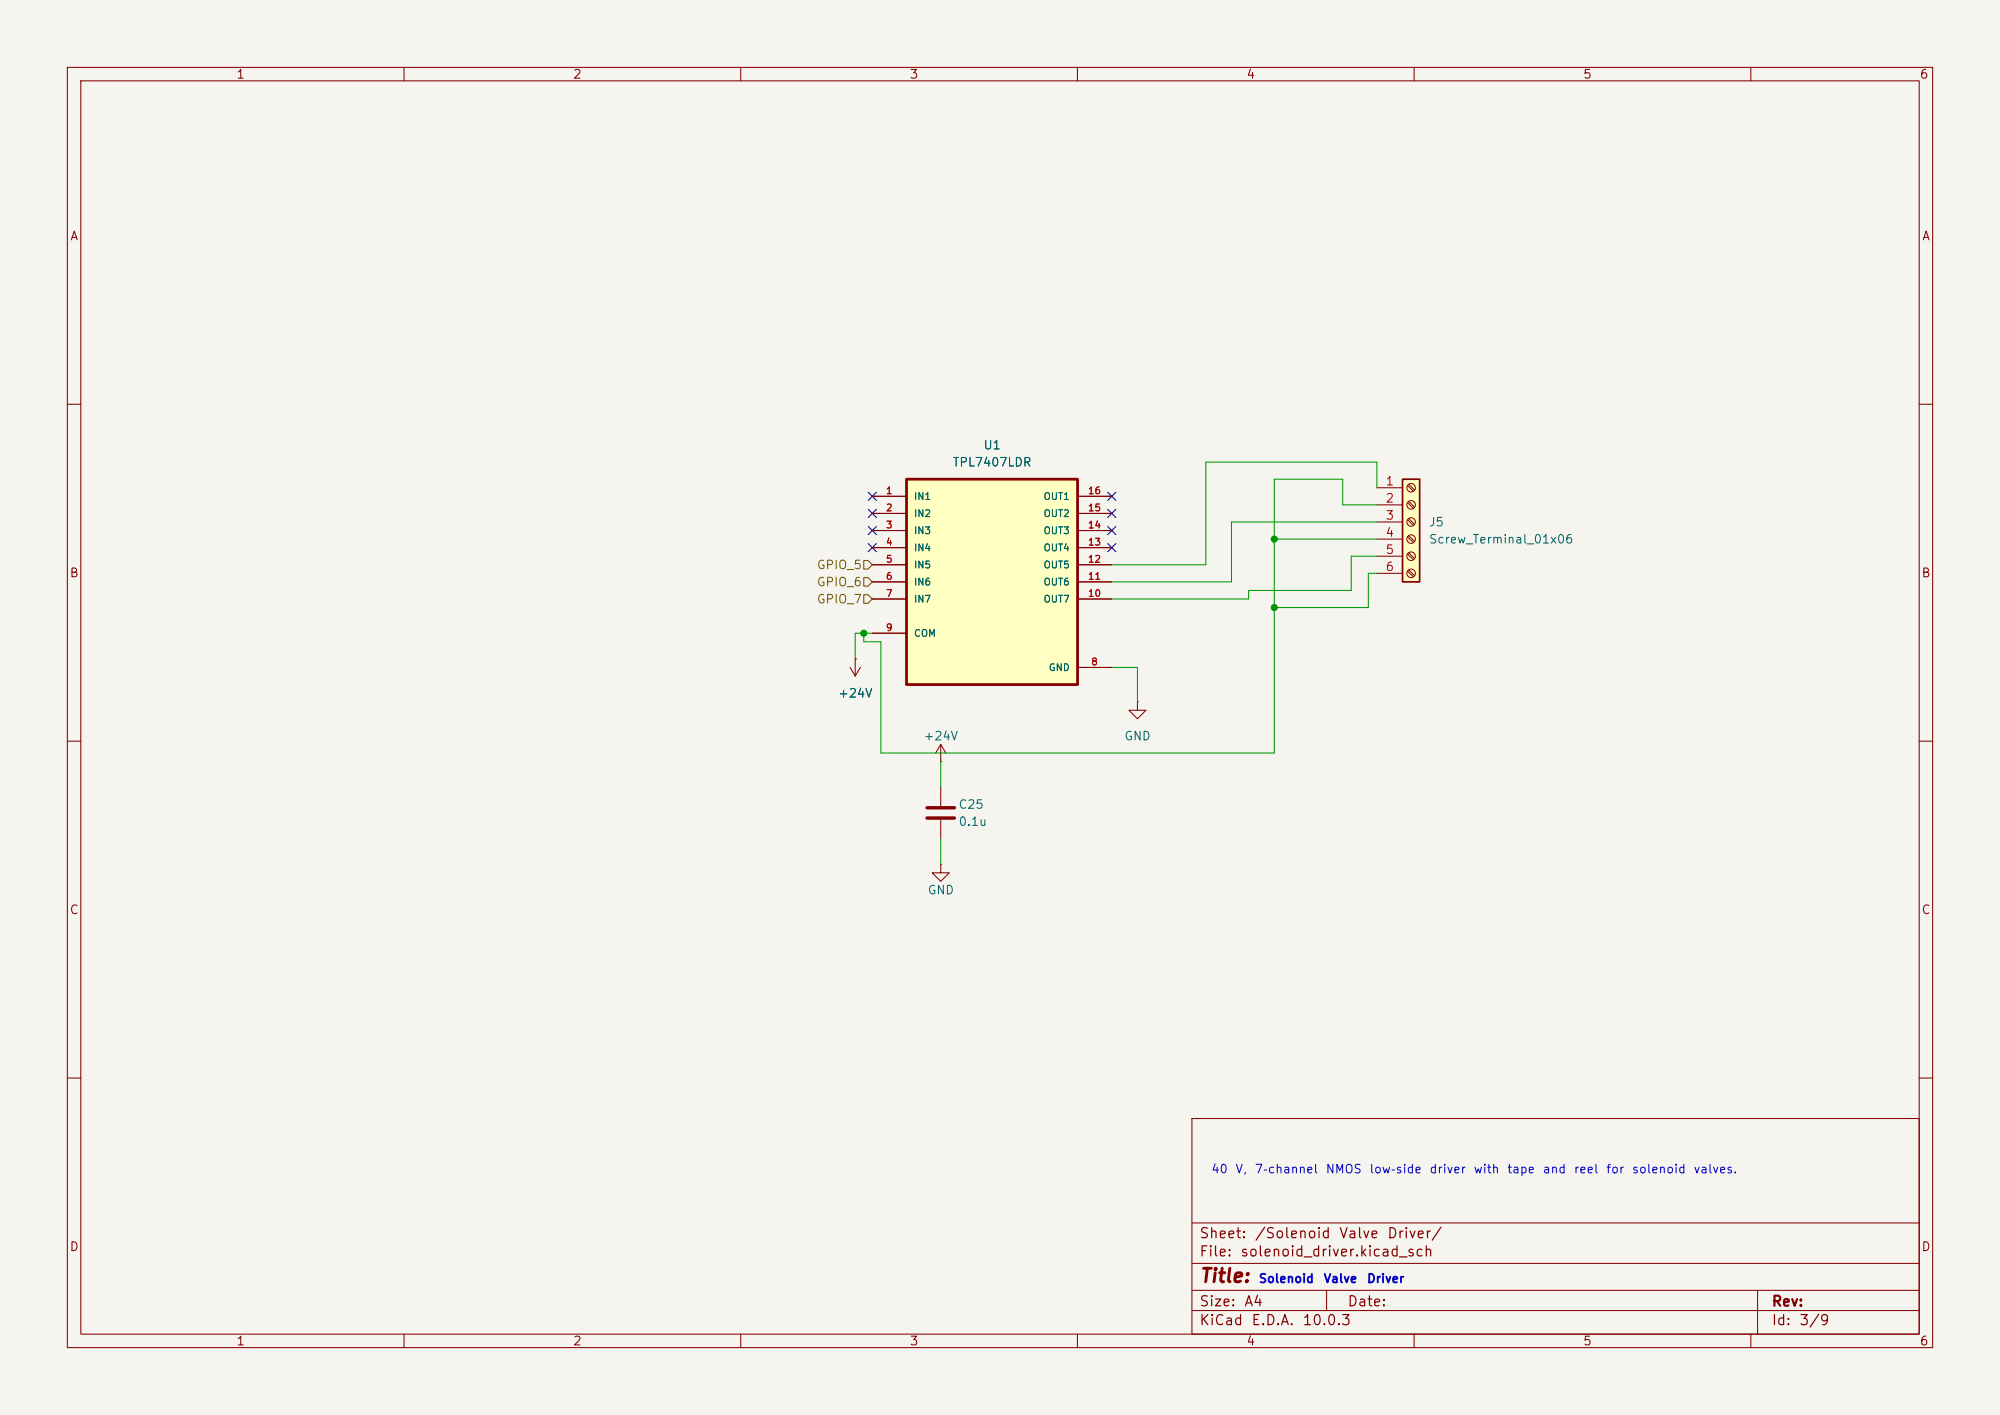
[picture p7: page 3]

40 V, 7‑channel NMOS low‑side driver with tape and reel for solenoid valves. Solenoid Valve Driver

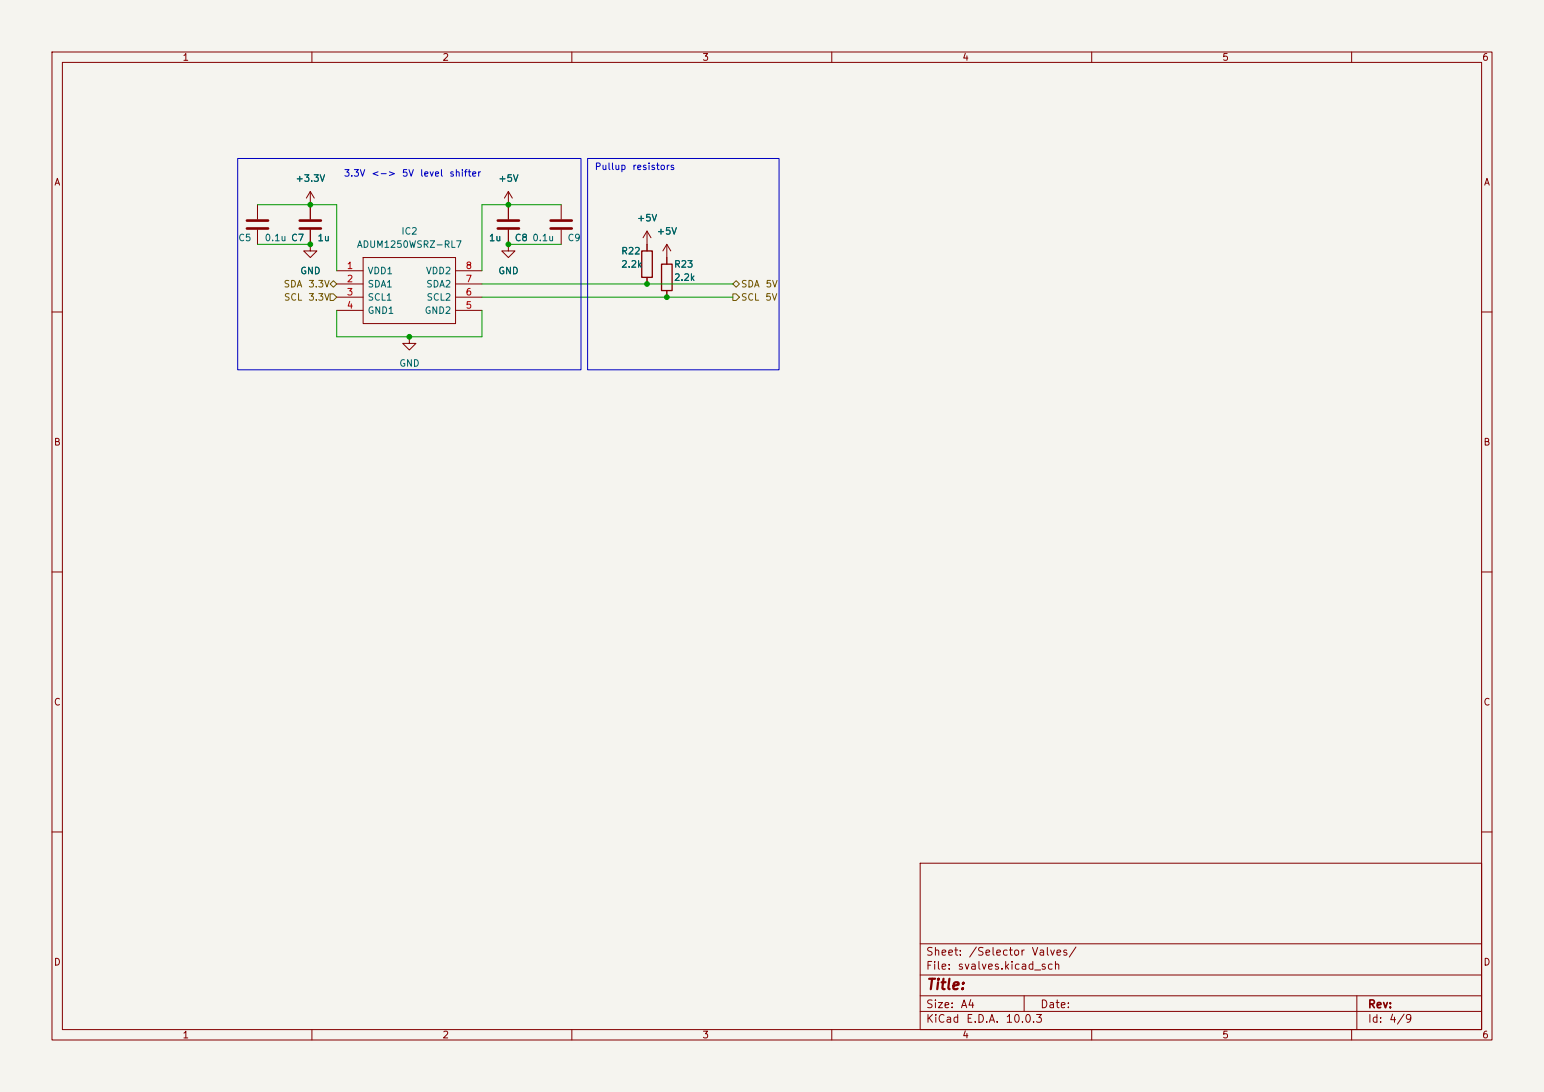
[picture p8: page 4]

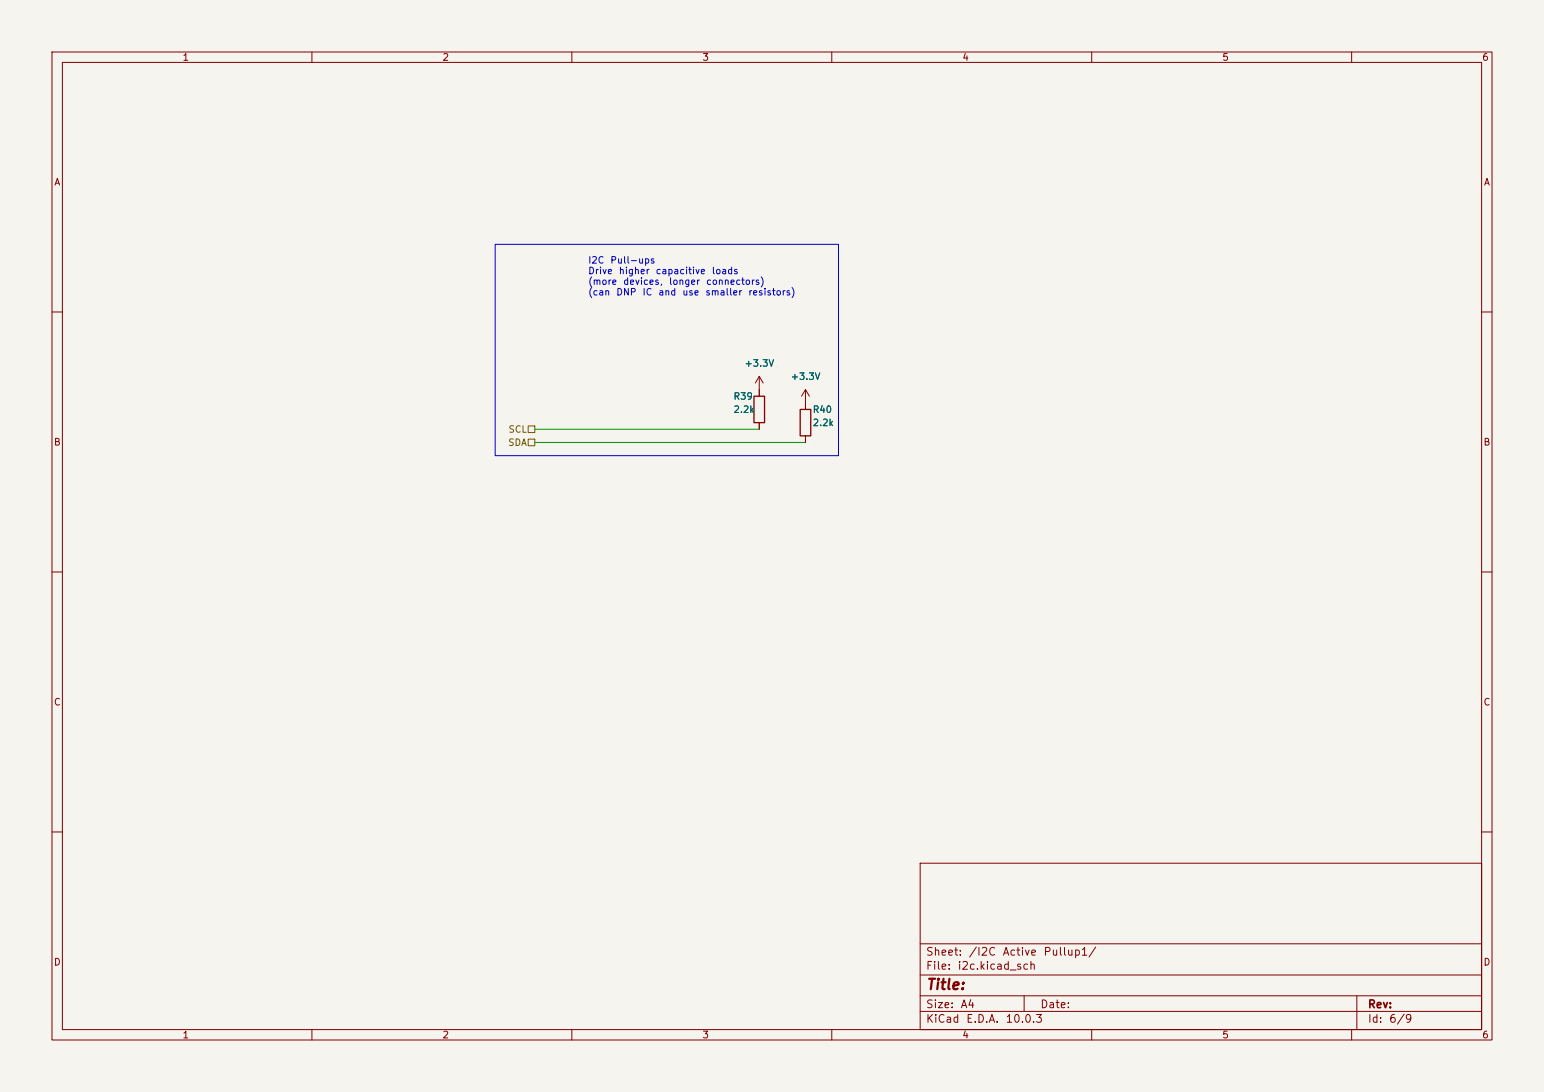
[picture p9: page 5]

I2C Pull-ups Drive higher capacitive loads

(more devices, longer connectors)
(can DNP IC and use smaller resistors) +3.3V R39

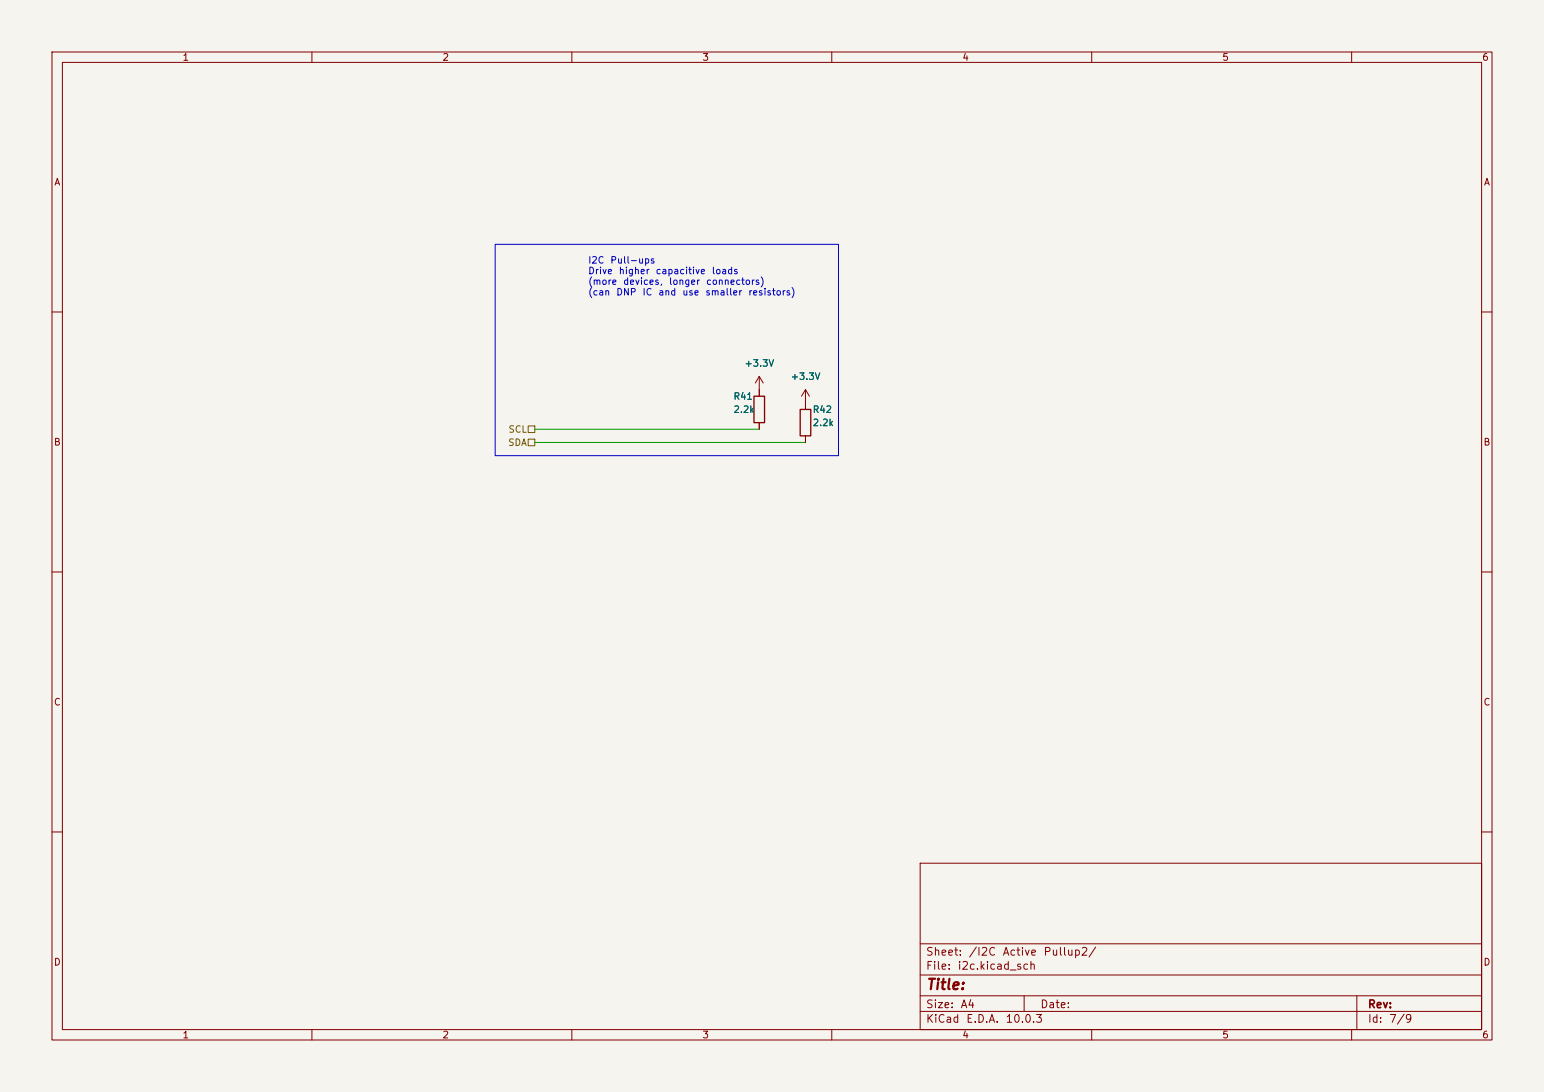
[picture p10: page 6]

I2C Pull-ups Drive higher capacitive loads

(more devices, longer connectors)

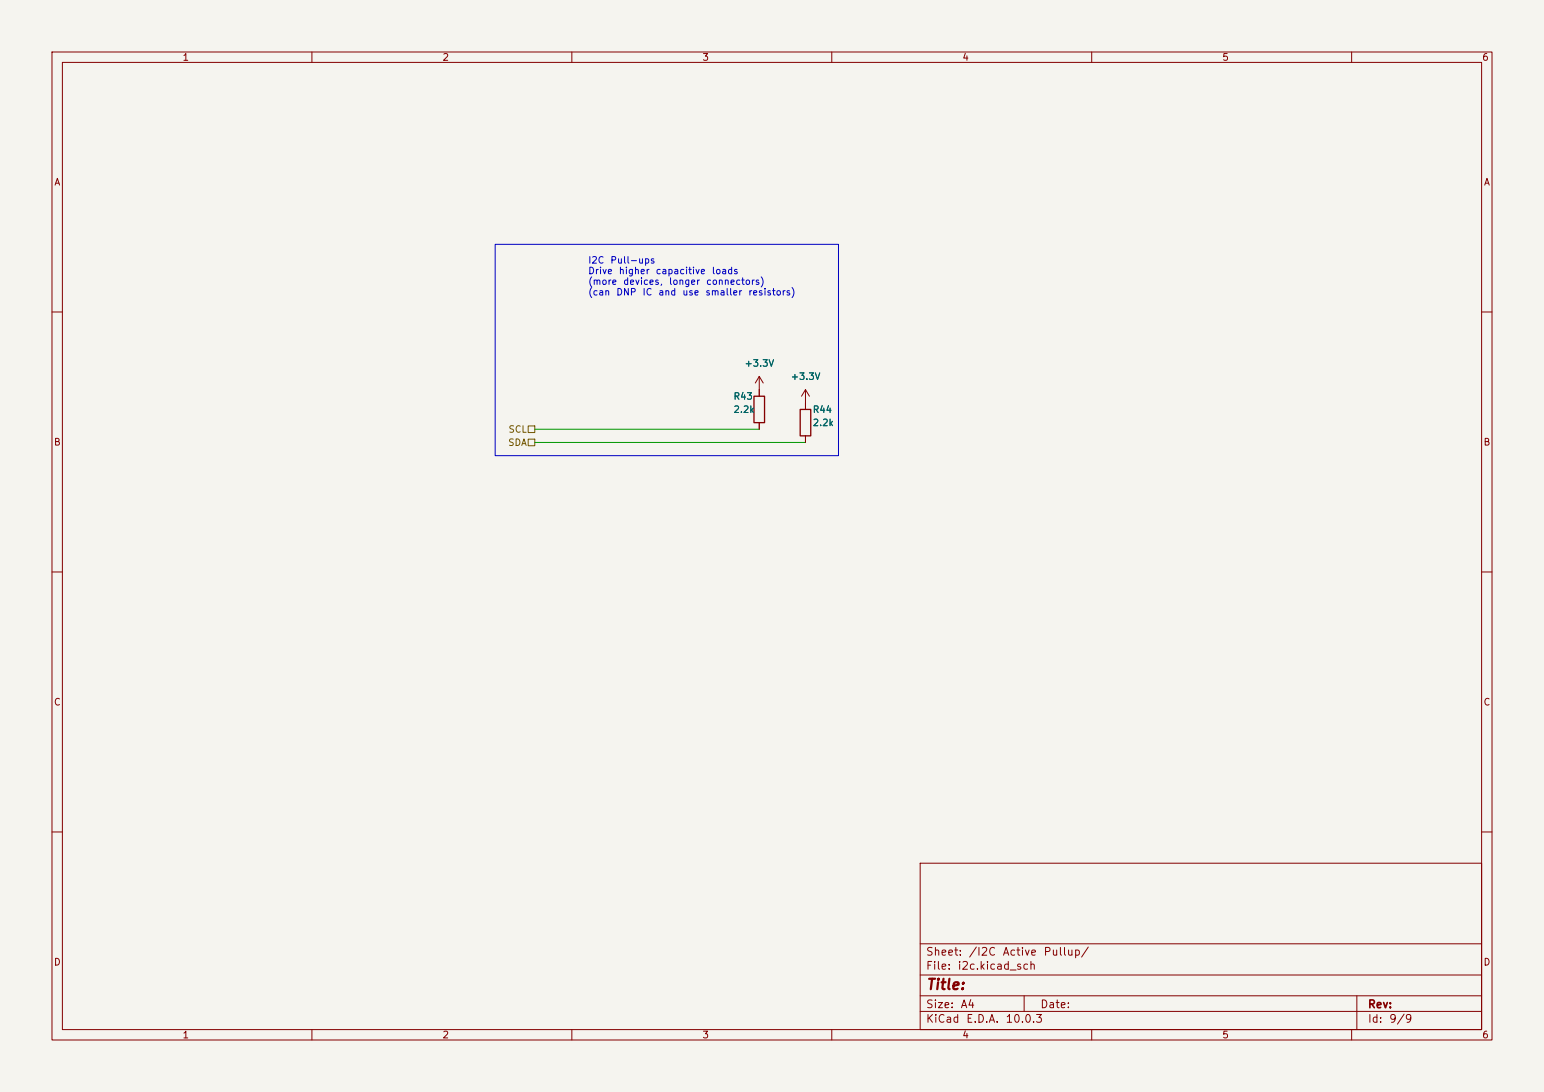
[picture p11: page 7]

I2C Pull-ups Drive higher capacitive loads

(more devices, longer connectors)
(can DNP IC and use smaller resistors) R43

AB

C

D

AB

C

D Date:

## Title:

File: syrpump.kicad_sch

Sheet: /Syringe Pump/

C17 | 0.1u C15 | 0.1u | GND

GND

C19 | 0.1u GND +3.3V C16 | 0.1u +3.3V GND

GND

EN 1 | C1+ 2
V+ | 3 C1- 4 | C2+ 5 | C2- 6
V- | 7 RIN | 8 ROUT 9
INVALID | 10 DIN 11
FORCEON 12 | DOUT | 13 GND 14 VCC 15
FORCEOFF | 16 U11 MAX3221 | +3.3V | C20 | 0.1u C18 | 1u | 232_TX UART_RX | 232_RX UART_TX

INVALID

Convert from 3.3V UART to RS232 C17 | 0.1u C16 | 0.1u C15 | 0.1u C18 | 1u GND | U11 MAX3221
EN 1 | C1+ 2
V+ | 3 C1- 4 | C2+ 5 | C2- 6
V- | 7 RIN | 8 ROUT 9
INVALID | 10 DIN 11
FORCEON 12 | DOUT | 13 GND 14 VCC 15
FORCEOFF | 16 GND+3.3V +3.3V | GND
C19 | 0.1u GND
C20 | 0.1u GND

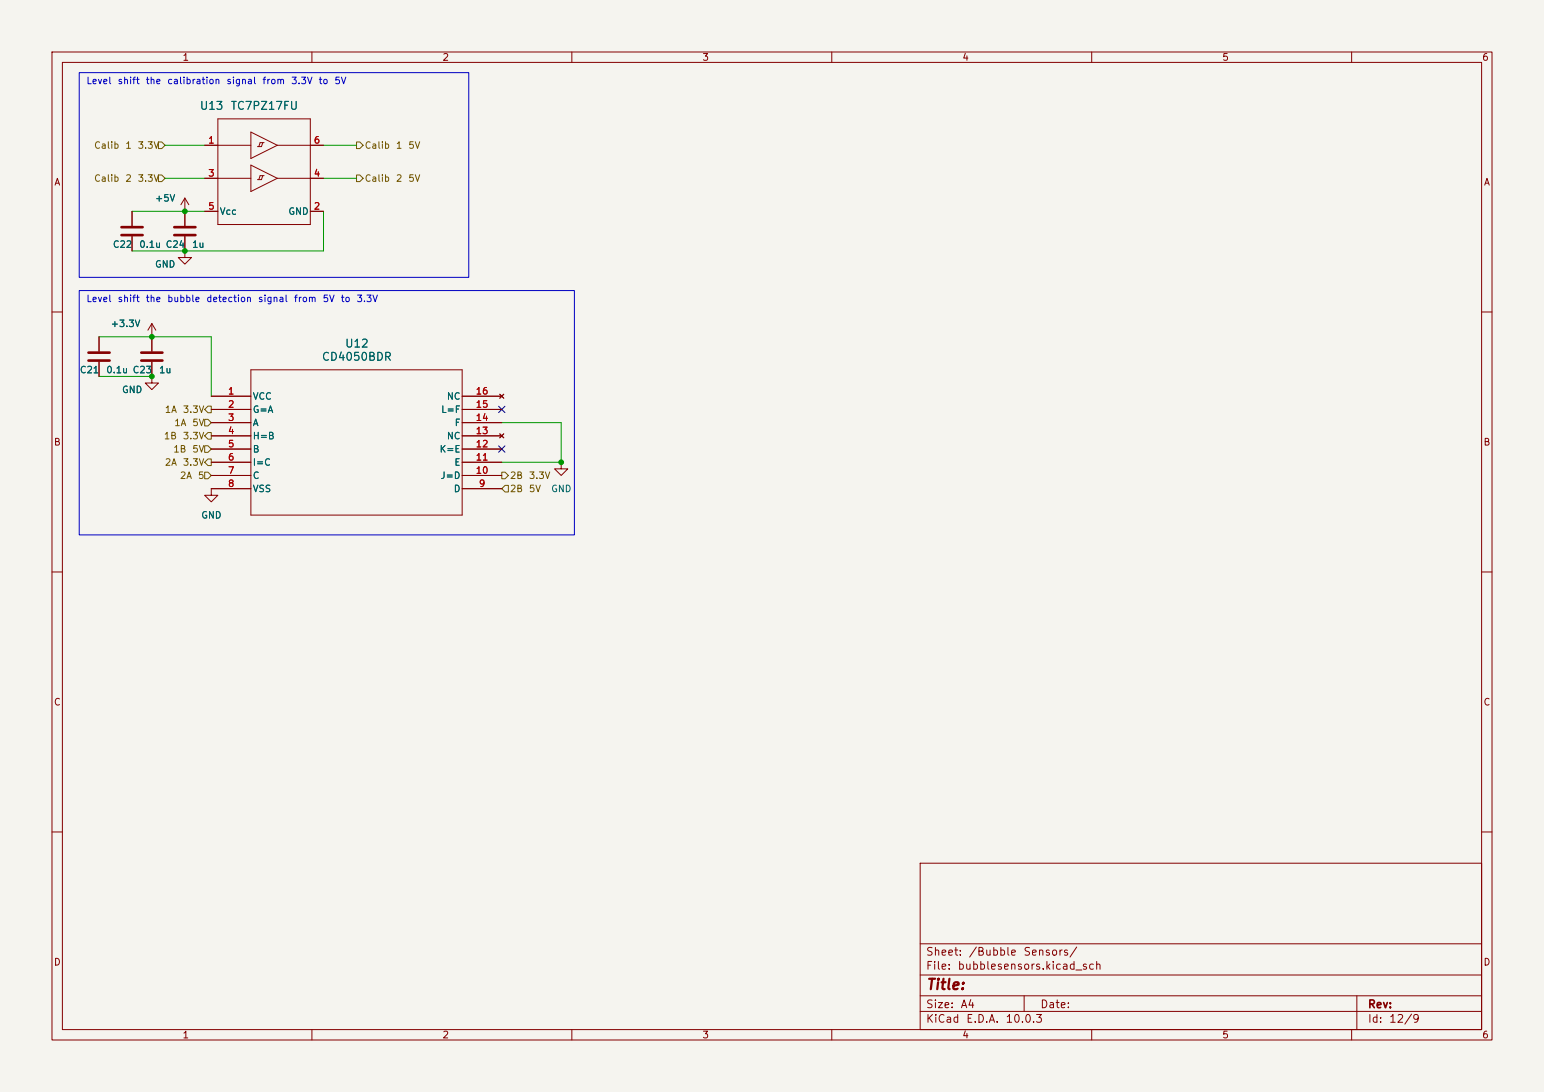
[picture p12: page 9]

Level shift the calibration signal from 3.3V to 5VU12
1A 3.3V 2A 3.3V Calib 1 3.3V 1B 3.3V 1B 5V

Level shift the bubble detection signal from 5V to 3.3V

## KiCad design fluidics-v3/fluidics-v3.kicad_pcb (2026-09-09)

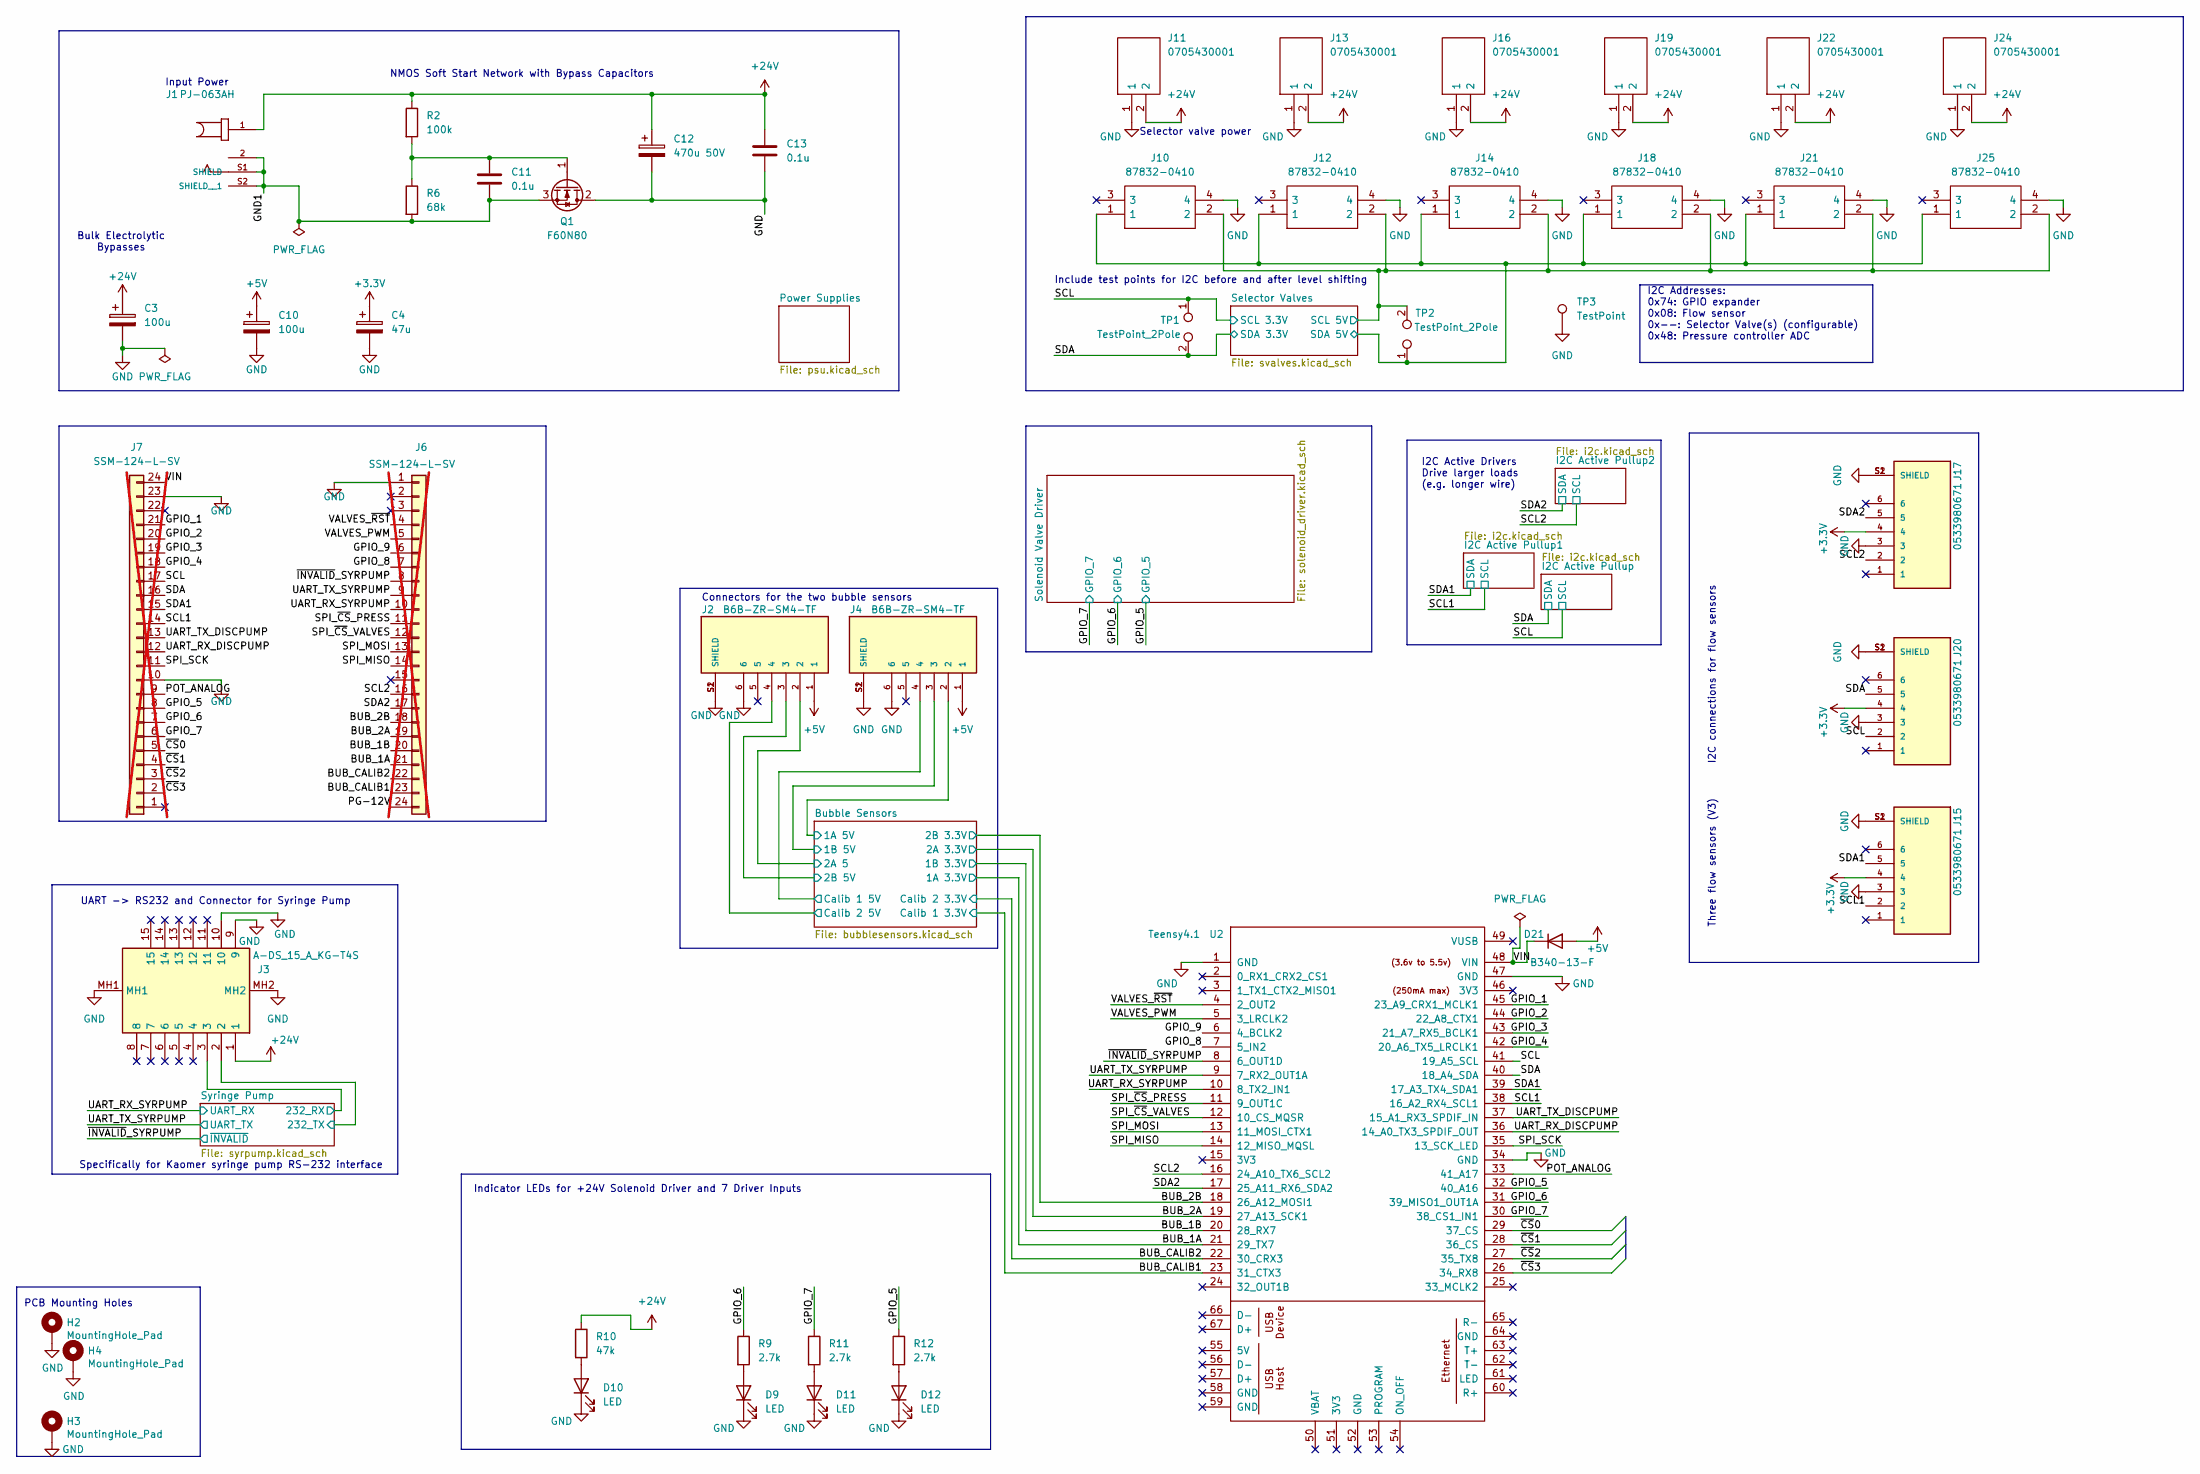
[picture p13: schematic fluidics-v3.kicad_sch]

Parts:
C3: 100u; CP_EIA-7343-20_Kemet-V
C4: 47u; C_1206_3216Metric
C10: 100u; C_1210_3225Metric
C11, C13: 0.1u; C_0603_1608Metric
C12: 470u 50V; CP_Radial_D10.0mm_P5.00mm
D9, D10, D11, D12: LED; LED_0402_1005Metric
D21: B340-13-F; D_SMC
H2, H3, H4: MountingHole_Pad; MountingHole_3.2mm_M3_Pad_Via
J1: PJ-063AH; CUI_PJ-063AH; Manufacturer_Part_Number PJ-063AH; LCSC C2928097
J2, J4: B6B-ZR-SM4-TF; CONN_B6B-ZR-SM4-TF_JST
J3: A-DS_15_A_KG-T4S; ADS15AKGT4S; Manufacturer_Part_Number A-DS 15 A/KG-T4S; LCSC C3100941
J6, J7: SSM-124-L-SV; PinSocket_1x24_P2.54mm_Vertical_SMD_DualLand; not fitted
J10, J12, J14, J18, J21, J25: 87832-0410; 878320410; Manufacturer_Part_Number 87832-0410; Mouser Part Number 538-87832-1010
J11, J13, J16, J19, J22, J24: 0705430001; SHDR2W64P0X254_1X2_737X660X1181P; Manufacturer_Part_Number 0705430001; Mouser Part Number N/A
J15, J17, J20: 0533980671; MOLEX_0533980671; PARTREV A
Q1: F60N80; TO-220-3_Vertical
R2: 100k; R_0402_1005Metric
R6: 68k; R_0402_1005Metric
R9, R11, R12: 2.7k; R_0402_1005Metric
R10: 47k; R_0603_1608Metric
TP1, TP2: TestPoint_2Pole; TestPoint_2Pads_Pitch2.54mm_Drill0.8mm
TP3: TestPoint; TestPoint_THTPad_1.5x1.5mm_Drill0.7mm
U2: Teensy4.1; Teensy 4.1

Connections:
+3.3V: C4.1, J15.4, J17.4, J20.4; also elsewhere on the board
+5V: C10.1, D21.2 (A), J2.1, J4.1; also elsewhere on the board
+24V: C3.1, C12.1, C13.1, J1.1, J3.1, J11.2, J13.2, J16.2, J19.2, J22.2, J24.2, R2.1, R10.1; also elsewhere on the board
/BUB_1A: J6.21, U2.21 (29_TX7); also elsewhere on the board
/BUB_1B: J6.20, U2.20 (28_RX7); also elsewhere on the board
/BUB_2A: J6.19, U2.19 (27_A13_SCK1); also elsewhere on the board
/BUB_2B: J6.18, U2.18 (26_A12_MOSI1); also elsewhere on the board
/BUB_CALIB1: J6.23, U2.23 (31_CTX3); also elsewhere on the board
/BUB_CALIB2: J6.22, U2.22 (30_CRX3); also elsewhere on the board
/Bubble Sensors/1A 5V: J4.2; also elsewhere on the board
/Bubble Sensors/1B 5V: J4.3; also elsewhere on the board
/Bubble Sensors/2A 5: J2.2; also elsewhere on the board
/Bubble Sensors/2B 5V: J2.3; also elsewhere on the board
/Bubble Sensors/Calib 1 5V: J4.4; also elsewhere on the board
/Bubble Sensors/Calib 2 5V: J2.4; also elsewhere on the board
/GND1: C11.2, J1.2, J1.S1 (SHIELD), J1.S2 (SHIELD__1), Q1.3 (S), R6.2
/GPIO_1: J7.21, U2.45 (23_A9_CRX1_MCLK1)
/GPIO_2: J7.20, U2.44 (22_A8_CTX1)
/GPIO_3: J7.19, U2.43 (21_A7_RX5_BCLK1)
/GPIO_4: J7.18, U2.42 (20_A6_TX5_LRCLK1)
/GPIO_5: J7.8, R12.1, U2.32 (40_A16); also elsewhere on the board
/GPIO_6: J7.7, R9.1, U2.31 (39_MISO1_OUT1A); also elsewhere on the board
/GPIO_7: J7.6, R11.1, U2.30 (38_CS1_IN1); also elsewhere on the board
/GPIO_8: J6.7, U2.7 (5_IN2)
/GPIO_9: J6.6, U2.6 (4_BCLK2)
/PG-12V: J6.24
/POT_ANALOG: J7.9, U2.33 (41_A17)
/SCL: J7.17, J20.2, TP1.1, U2.41 (19_A5_SCL); also elsewhere on the board
/SCL1: J7.14, J15.2, U2.38 (16_A2_RX4_SCL1); also elsewhere on the board
/SCL2: J6.16, J17.2, U2.16 (24_A10_TX6_SCL2); also elsewhere on the board
/SDA: J7.16, J20.5, TP1.2, U2.40 (18_A4_SDA); also elsewhere on the board
/SDA1: J7.15, J15.5, U2.39 (17_A3_TX4_SDA1); also elsewhere on the board
/SDA2: J6.17, J17.5, U2.17 (25_A11_RX6_SDA2); also elsewhere on the board
/SPI_MISO: J6.14, U2.14 (12_MISO_MQSL)
/SPI_MOSI: J6.13, U2.13 (11_MOSI_CTX1)
/SPI_SCK: J7.11, U2.35 (13_SCK_LED)
/SPI_~CS_PRESS: J6.11, U2.11 (9_OUT1C)
/SPI_~CS_VALVES: J6.12, U2.12 (10_CS_MQSR)
/Selector Valves/SCL 5V: J10.2, J12.2, J14.2, J18.2, J21.2, J25.2, TP2.2; also elsewhere on the board
/Selector Valves/SDA 5V: J10.1, J12.1, J14.1, J18.1, J21.1, J25.1, TP2.1; also elsewhere on the board
/Syringe Pump/232_RX: J3.3; also elsewhere on the board
/Syringe Pump/232_TX: J3.2; also elsewhere on the board
/UART_RX_DISCPUMP: J7.12, U2.36 (14_A0_TX3_SPDIF_OUT)
/UART_RX_SYRPUMP: J6.10, U2.10 (8_TX2_IN1); also elsewhere on the board
/UART_TX_DISCPUMP: J7.13, U2.37 (15_A1_RX3_SPDIF_IN)
/UART_TX_SYRPUMP: J6.9, U2.9 (7_RX2_OUT1A); also elsewhere on the board
/VALVES_PWM: J6.5, U2.5 (3_LRCLK2)
/VALVES_~RST: J6.4, U2.4 (2_OUT2)
/VIN: D21.1 (K), J7.24, U2.48 (VIN)
/~CS0: J7.5, U2.29 (37_CS)
/~CS1: J7.4, U2.28 (36_CS)
/~CS2: J7.3, U2.27 (35_TX8)
/~CS3: J7.2, U2.26 (34_RX8)
/~INVALID_SYRPUMP: J6.8, U2.8 (6_OUT1D); also elsewhere on the board
GND: C3.2, C4.2, C10.2, C12.2, C13.2, D9.1 (K), D10.1 (K), D11.1 (K), D12.1 (K), H2.1 (1_1), H3.1 (1_1), H4.1 (1_1), J2.6, J2.S1 (SHIELD), J2.S2 (SHIELD), J3.9, J3.10, J3.MH1, J3.MH2, J4.6, J4.S1 (SHIELD), J4.S2 (SHIELD), J6.1, J7.10, J7.23, J10.4, J11.1, J12.4, J13.1, J14.4, J15.3, J15.S1 (SHIELD), J15.S2 (SHIELD), J16.1, J17.3, J17.S1 (SHIELD), J17.S2 (SHIELD), J18.4, J19.1, J20.3, J20.S1 (SHIELD), J20.S2 (SHIELD), J21.4, J22.1, J24.1, J25.4, Q1.2 (D), TP3.1 (1_1), U2.1 (GND), U2.34 (GND), U2.47 (GND); also elsewhere on the board
unnamed: D9.2 (A), R9.2
unnamed: D10.2 (A), R10.2
unnamed: D11.2 (A), R11.2
unnamed: D12.2 (A), R12.2
unnamed: C11.1, Q1.1 (G), R2.2, R6.1

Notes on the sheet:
I2C connections for flow sensors
NMOS Soft Start Network with Bypass Capacitors
Indicator LEDs for +24V Solenoid Driver and 7 Driver Inputs
Bulk Electrolytic Bypasses
Three flow sensors (V3)
Include test points for I2C before and after level shifting
UART -> RS232 and Connector for Syringe Pump
PCB Mounting Holes
Input Power
Selector valve power
I2C Addresses: 0x74: GPIO expander 0x08: Flow sensor 0x--: Selector Valve(s) (configurable) 0x48: Pressure controller ADC
Specifically for Kaomer syringe pump RS-232 interface
Connectors for the two bubble sensors
I2C Active Drivers Drive larger loads (e.g. longer wire)

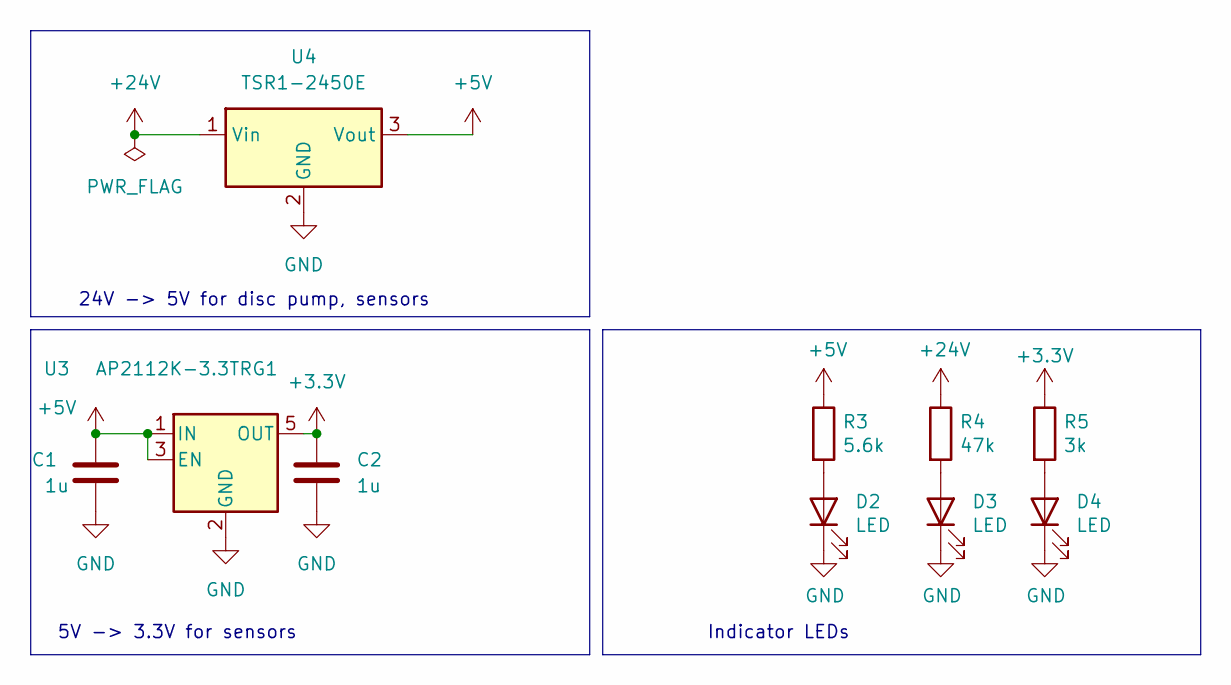
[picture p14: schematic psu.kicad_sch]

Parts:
C1, C2: 1u; C_0603_1608Metric
D2, D3: LED; LED_0805_2012Metric; Manufacturer_Part_Number LTST-C170TGKT; LCSC Part # C73546
D4: LED; LED_0805_2012Metric; Manufacturer_Part_Number EAST2012WA1; LCSC Part # C83960
R3: 5.6k; R_0805_2012Metric; Manufacturer_Part_Number RC0805FR-075K6L
R4: 47k; R_0402_1005Metric; Manufacturer_Part_Number RC0402FR-0747KL
R5: 3k; R_0402_1005Metric; Manufacturer_Part_Number RC0402FR-073KL
U3: AP2112K-3.3TRG1; SOT-23-5
U4: TSR1-2450E; Converter_DCDC_TRACO_TSR1-xxxxE_THT

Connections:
+3.3V: C2.1, R5.1, U3.5 (OUT); also elsewhere on the board
+5V: C1.1, R3.1, U3.1 (IN), U3.3 (EN), U4.3 (Vout); also elsewhere on the board
+24V: R4.1, U4.1 (Vin); also elsewhere on the board
GND: C1.2, C2.2, D2.1 (K), D3.1 (K), D4.1 (K), U3.2 (GND), U4.2 (GND); also elsewhere on the board
unnamed: D2.2 (A), R3.2
unnamed: D3.2 (A), R4.2
unnamed: D4.2 (A), R5.2

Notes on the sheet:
5V -> 3.3V for sensors
24V -> 5V for disc pump, sensors
Indicator LEDs

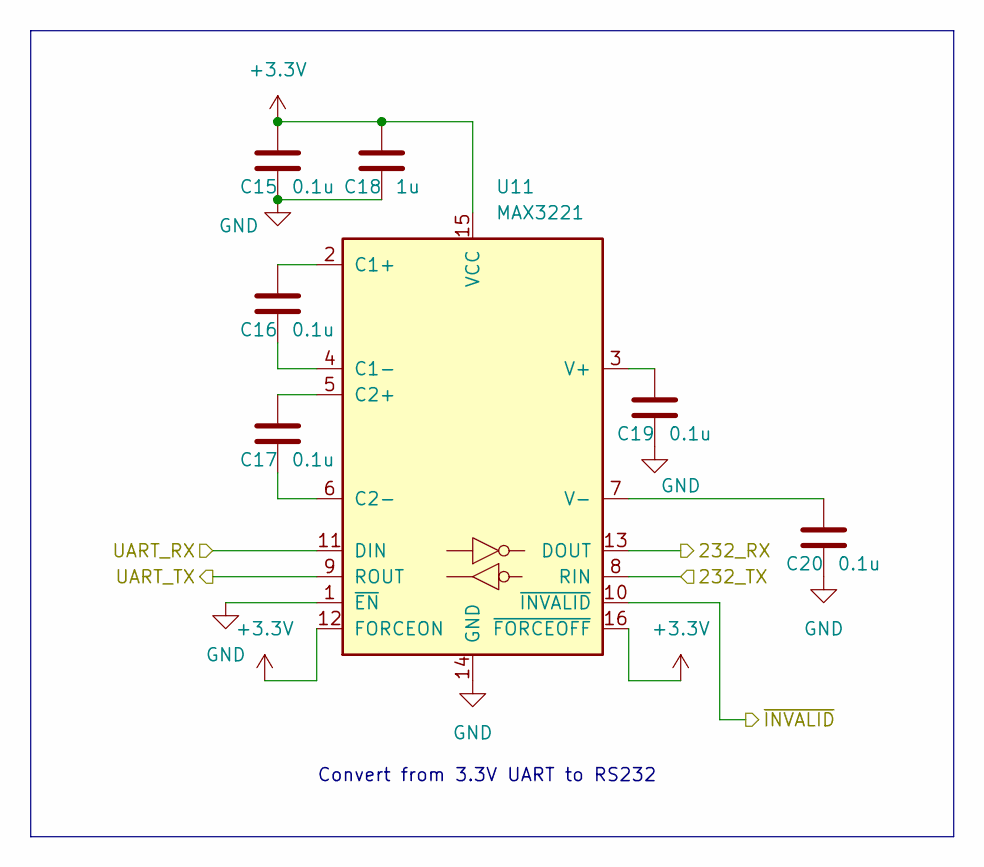
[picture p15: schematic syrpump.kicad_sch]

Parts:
C15, C16, C17, C19, C20: 0.1u; C_0603_1608Metric
C18: 1u; C_0805_2012Metric
U11: MAX3221; SOP65P640X120-16N

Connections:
+3.3V: C15.1, C18.1, U11.12 (FORCEON), U11.15 (VCC), U11.16 (~FORCEOFF); also elsewhere on the board
/Syringe Pump/232_RX: U11.13 (DOUT); also elsewhere on the board
/Syringe Pump/232_TX: U11.8 (RIN); also elsewhere on the board
/UART_RX_SYRPUMP: U11.11 (DIN); also elsewhere on the board
/UART_TX_SYRPUMP: U11.9 (ROUT); also elsewhere on the board
/~INVALID_SYRPUMP: U11.10 (~INVALID); also elsewhere on the board
GND: C15.2, C18.2, C19.2, C20.2, U11.1 (~EN), U11.14 (GND); also elsewhere on the board
unnamed: C16.1, U11.2 (C1+)
unnamed: C16.2, U11.4 (C1-)
unnamed: C17.1, U11.5 (C2+)
unnamed: C17.2, U11.6 (C2-)
unnamed: C19.1, U11.3 (V+)
unnamed: C20.1, U11.7 (V-)

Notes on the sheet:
Convert from 3.3V UART to RS232

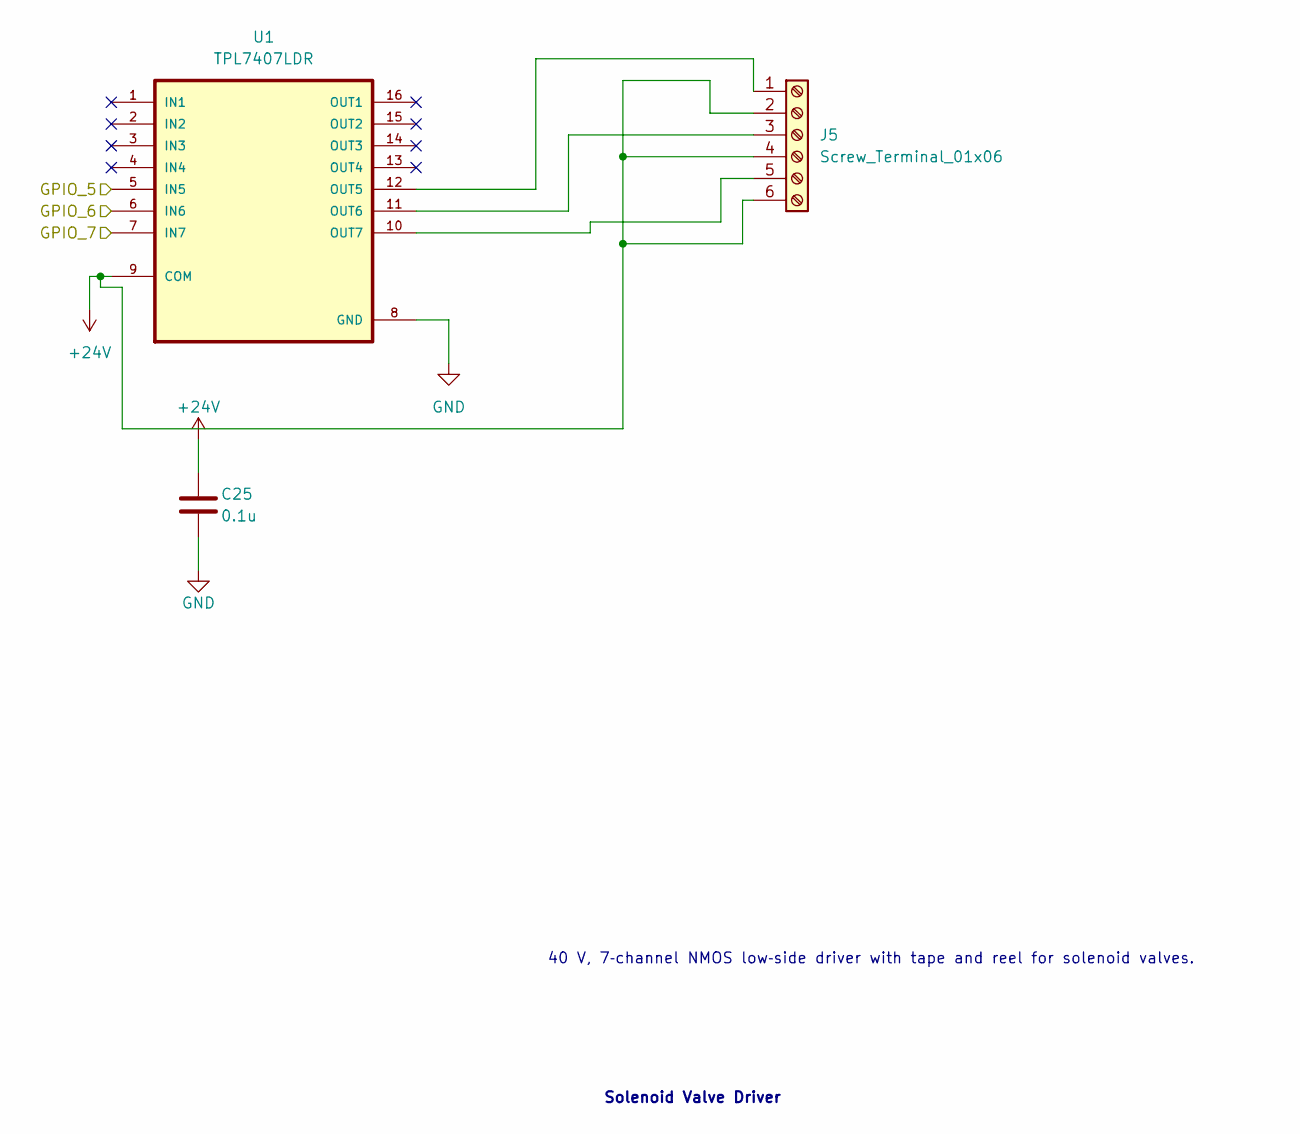
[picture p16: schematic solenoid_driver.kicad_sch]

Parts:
C25: 0.1u; C_0603_1608Metric
J5: Screw_Terminal_01x06; TerminalBlock_Xinya_XY308-2.54-6P_1x06_P2.54mm_Horizontal
U1: TPL7407LDR; SOIC127P600X175-16N; Manufacturer_Part_Number TPL7407LDR

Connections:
+24V: C25.1, J5.2, J5.4, J5.6, U1.9 (COM); also elsewhere on the board
/GPIO_5: U1.5 (IN5); also elsewhere on the board
/GPIO_6: U1.6 (IN6); also elsewhere on the board
/GPIO_7: U1.7 (IN7); also elsewhere on the board
GND: C25.2, U1.8 (GND); also elsewhere on the board
unnamed: J5.1, U1.12 (OUT5)
unnamed: J5.3, U1.11 (OUT6)
unnamed: J5.5, U1.10 (OUT7)

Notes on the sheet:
Solenoid Valve Driver
40 V, 7‑channel NMOS low‑side driver with tape and reel for solenoid valves.

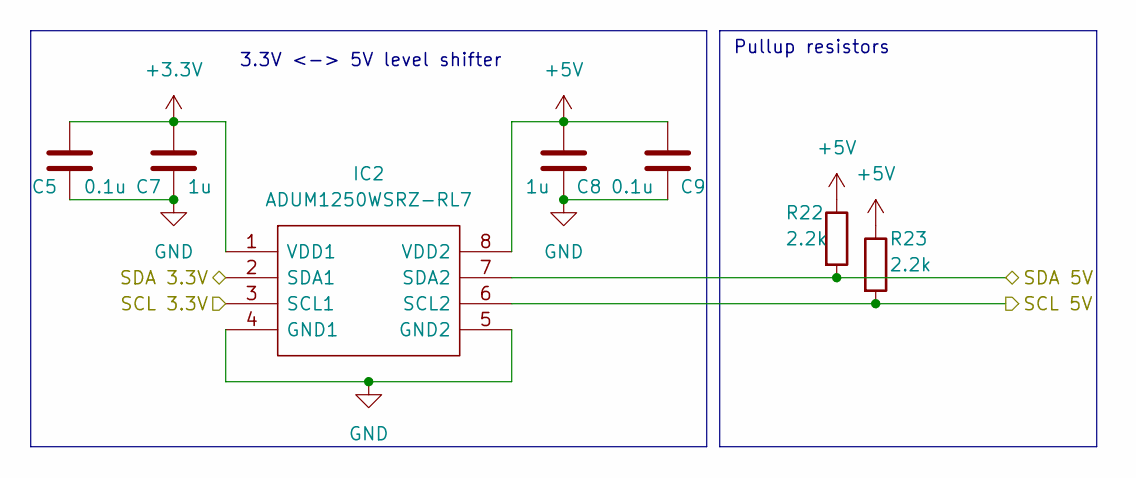
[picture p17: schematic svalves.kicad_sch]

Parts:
C5, C9: 0.1u; C_0603_1608Metric
C7, C8: 1u; C_0805_2012Metric
IC2: ADUM1250WSRZ-RL7; SOIC127P600X175-8N; Manufacturer_Part_Number ADUM1250WSRZ-RL7; Mouser Part Number 584-ADUM1250WSRZ-RL7
R22, R23: 2.2k; R_0402_1005Metric

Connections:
+3.3V: C5.1, C7.1, IC2.1 (VDD1); also elsewhere on the board
+5V: C8.1, C9.1, IC2.8 (VDD2), R22.1, R23.1; also elsewhere on the board
/SCL: IC2.3 (SCL1); also elsewhere on the board
/SDA: IC2.2 (SDA1); also elsewhere on the board
/Selector Valves/SCL 5V: IC2.6 (SCL2), R23.2; also elsewhere on the board
/Selector Valves/SDA 5V: IC2.7 (SDA2), R22.2; also elsewhere on the board
GND: C5.2, C7.2, C8.2, C9.2, IC2.4 (GND1), IC2.5 (GND2); also elsewhere on the board

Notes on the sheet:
Pullup resistors
3.3V <-> 5V level shifter

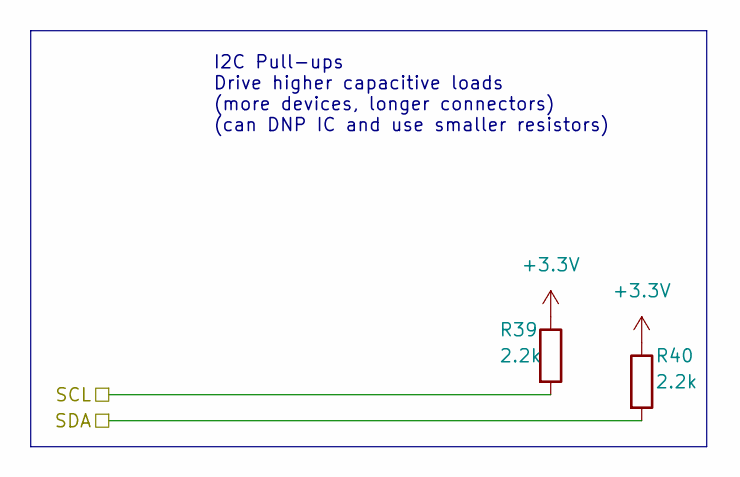
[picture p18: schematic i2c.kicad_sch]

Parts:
R39, R40: 2.2k; R_0402_1005Metric

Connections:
+3.3V: R39.1, R40.1; also elsewhere on the board
/SCL1: R39.2; also elsewhere on the board
/SDA1: R40.2; also elsewhere on the board

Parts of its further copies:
R41, R42, R43, R44: 2.2k; R_0402_1005Metric

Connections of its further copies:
+3.3V: R41.1, R42.1, R43.1, R44.1; also elsewhere on the board
/SCL: R43.2; also elsewhere on the board
/SCL2: R41.2; also elsewhere on the board
/SDA: R44.2; also elsewhere on the board
/SDA2: R42.2; also elsewhere on the board

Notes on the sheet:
I2C Pull-ups Drive higher capacitive loads (more devices, longer connectors) (can DNP IC and use smaller resistors)

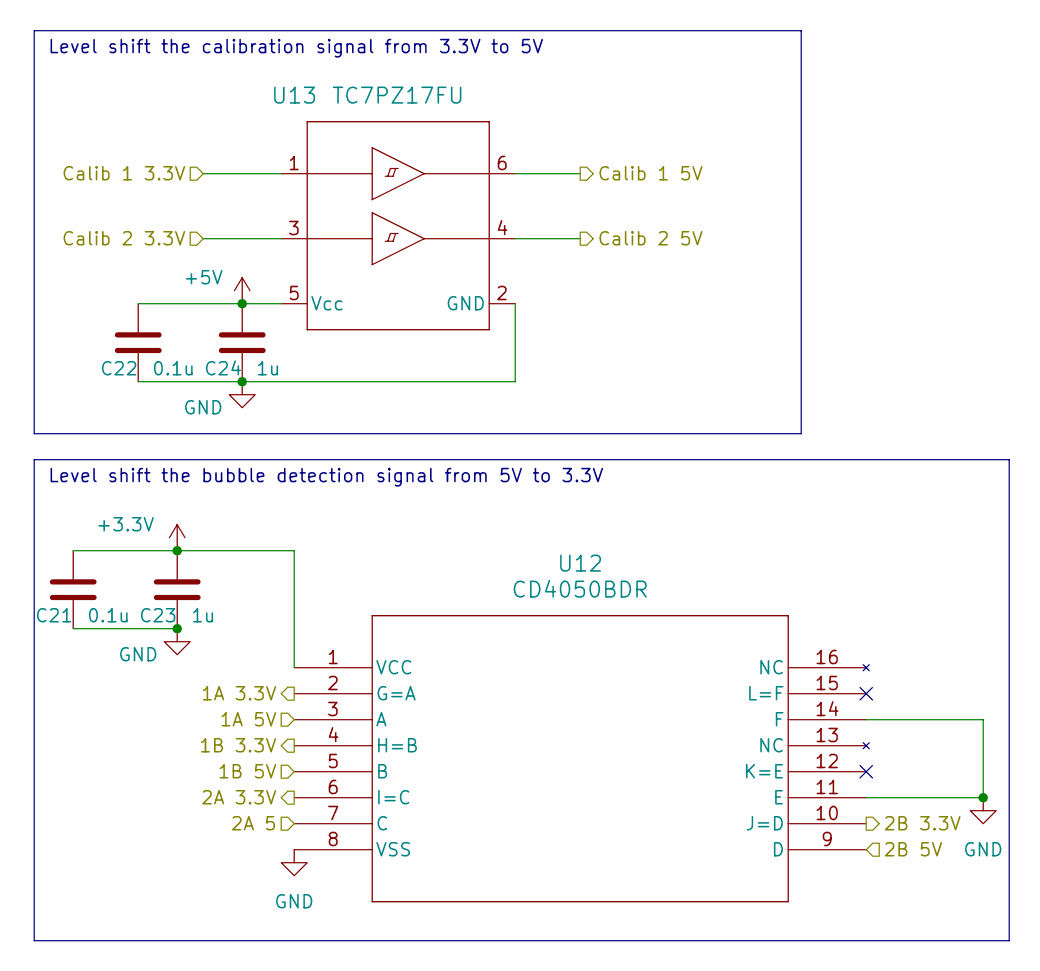
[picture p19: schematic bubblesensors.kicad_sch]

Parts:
C21, C22: 0.1u; C_0603_1608Metric
C23, C24: 1u; C_0805_2012Metric
U12: CD4050BDR; D16
U13: TC7PZ17FU; SOT-363 US6_TOS

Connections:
+3.3V: C21.1, C23.1, U12.1 (VCC); also elsewhere on the board
+5V: C22.1, C24.1, U13.5 (Vcc); also elsewhere on the board
/BUB_1A: U12.2 (G=A); also elsewhere on the board
/BUB_1B: U12.4 (H=B); also elsewhere on the board
/BUB_2A: U12.6 (I=C); also elsewhere on the board
/BUB_2B: U12.10 (J=D); also elsewhere on the board
/BUB_CALIB1: U13.1; also elsewhere on the board
/BUB_CALIB2: U13.3; also elsewhere on the board
/Bubble Sensors/1A 5V: U12.3 (A); also elsewhere on the board
/Bubble Sensors/1B 5V: U12.5 (B); also elsewhere on the board
/Bubble Sensors/2A 5: U12.7 (C); also elsewhere on the board
/Bubble Sensors/2B 5V: U12.9 (D); also elsewhere on the board
/Bubble Sensors/Calib 1 5V: U13.6; also elsewhere on the board
/Bubble Sensors/Calib 2 5V: U13.4; also elsewhere on the board
GND: C21.2, C22.2, C23.2, C24.2, U12.8 (VSS), U12.11 (E), U12.14 (F), U13.2 (GND); also elsewhere on the board

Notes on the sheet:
Level shift the bubble detection signal from 5V to 3.3V
Level shift the calibration signal from 3.3V to 5V

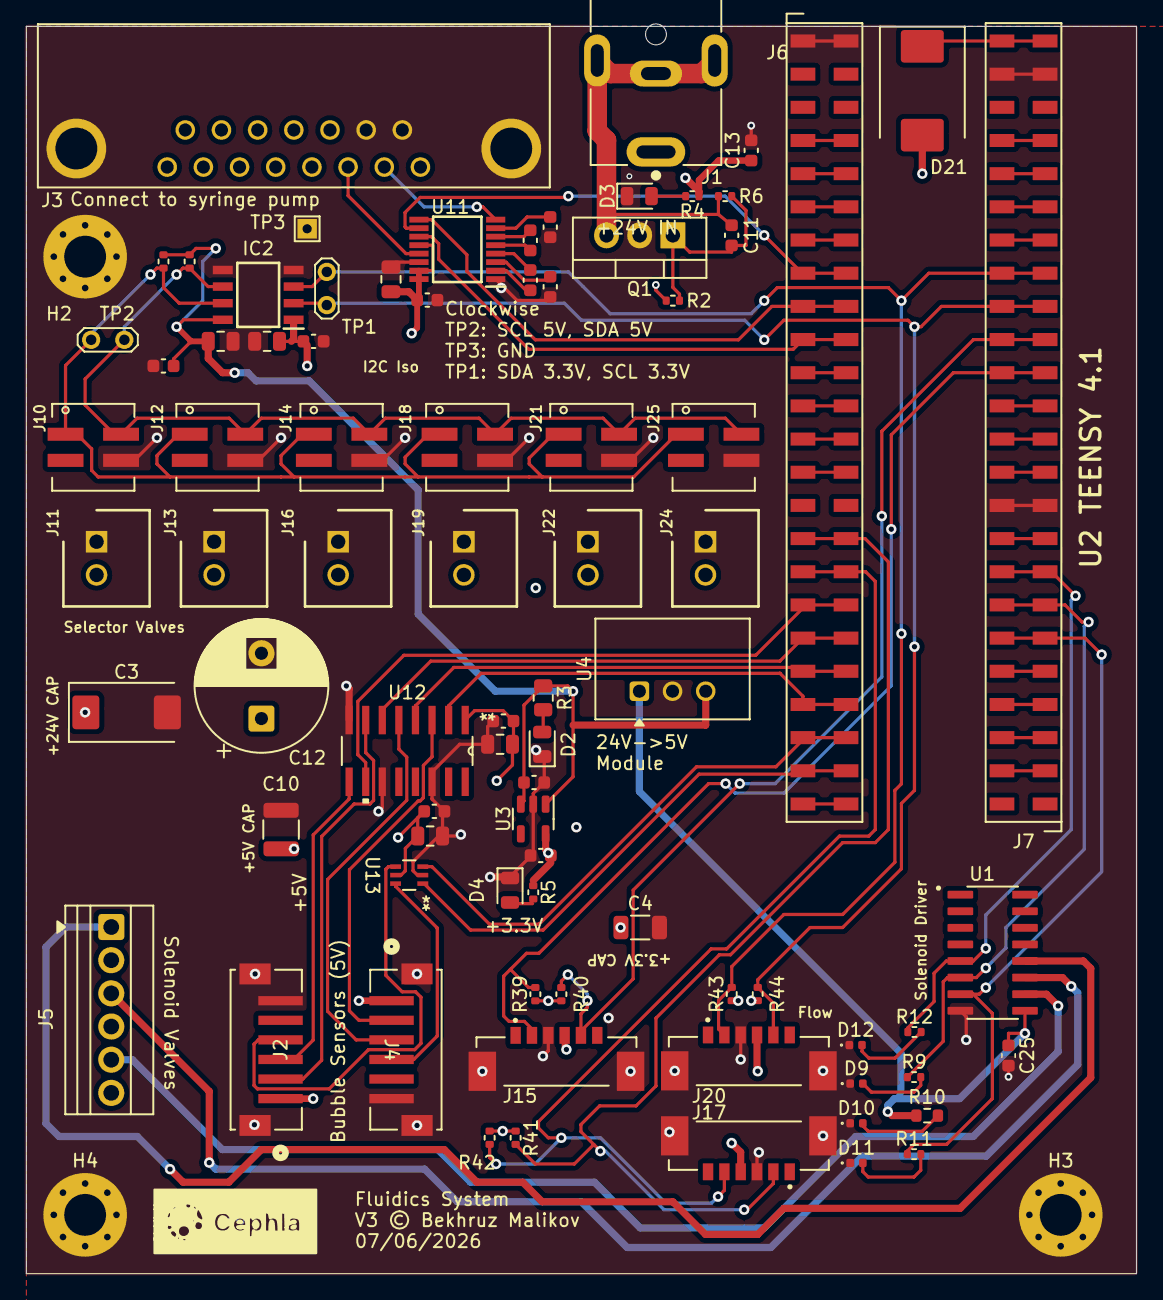
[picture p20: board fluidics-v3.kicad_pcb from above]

Board: 4 copper layers, 85.0 x 95.5 mm, 84 parts (0 on the bottom side), 51 nets.

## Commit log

2026-06-25 V3: strip to minimal fluidics config, add 6th selector valve, fix lib paths
    Reduce the V2 fluidics controller to a minimal build and extend the
    selector-valve bank:
    - Remove disc-pump driver (U1, M1); keep the syringe pump only
    - Remove the solenoid-valve subsystem (MCZ33996 IC1 + D5-D20 + R6-R21
    + connector J5) -- 16 solenoids -> 0
    - Remove all SPI pressure sensors (IC3-IC6 and their passives) -- 4 -> 0
    - Reduce I2C flow sensors 4 -> 3 (drop connector J17)
    - Add a 6th IDEX selector-valve channel (connectors J24/J25) on the
    shared isolated-I2C + 24V bus
    - Remove the Wenzel-lab pressure-controller daughter board interface
    (J6, J7/ICSP, J8, JP3)
    - Remove the manual-control block (switch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
    [bubblesensors.kicad_sch, fluidics-v2.kicad_pcb, fluidics-v2.kicad_sch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]
2026-06-25 Add V3_CHANGES.md documenting the strip-down rationale
    Written record of what changed in V3 and why: per-subsystem removals
    (disc pump, solenoids, pressure sensors, one flow sensor, Wenzel
    pressure-controller daughter board, manual control, 24V->12V converter),
    the added 6th selector-valve channel, the library-path portability fix,
    the 177->86 footprint reduction, and the still-open board-resize TODO.
2026-06-30 @ WIP: continue strip-down — empty sensors sheet, drop 11 PCB footprints
    Recovered in-progress work from the previous KiCad session (restored via
    KiCad session recovery). This is mid-edit, not a finished config:
    - sensors.kicad_sch: 17 -> 0 symbols (sheet fully emptied)
    - fluidics-v2.kicad_pcb: 86 -> 75 footprints
    - fluidics-v2.kicad_sch: minor net/sheet cleanup
    Schematic + libraries validated with kicad-cli sch export netlist (exit 0).
    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
    [fluidics-v2.kicad_pcb, fluidics-v2.kicad_sch, sensors.kicad_sch]
2026-07-02 @ Remove J9 daughterboard connector; restore Back GND plane; fix thermals
    - Delete J9 (20-pin FPC to motor-control daughterboard) from PCB + schematic;
    its SPI/GPIO went nowhere else on-board (75 -> 74 footprints)
    - Remove orphaned GPIO_1-9 / SPI_MOSI / SPI_MISO copper (72 tracks, 11 vias)
    plus the ex-J9 dangling stub vias on the I2C/SCK buses
    - Reassign the floating no-net Back pour to GND: clears isolated_copper and
    restores a continuous back-side ground plane
    - Set U4/J15/D2 GND pads to solid zone connection: clears starved_thermal
    - DRC: 229 -> 217 violations. starved_thermal 3->0, isolated_copper 1->0,
    via_dangling 7->0. Remaining ~217 are cosmetic silk/courtyard/library
    warni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
    [fluidics-v2.kicad_pcb, fluidics-v2.kicad_sch]
2026-07-02 @ Add TPL7407LDR library, project-local (portable)
    Vendor export (SOIC-16 low-side driver) was registered from an absolute
    Downloads path. Copied into the project and re-pointed both lib tables to
    ${KIPRJMOD}/../ so it travels with the repo, matching existing convention:
    - symbol -> User KiCad Library/user-symbols/TPL7407LDR.kicad_sym
    - footprint-> User KiCad Library/TPL7407LDR.pretty/SOIC127P600X175-16N.kicad_mod
    - 3D model -> User KiCad Library/user-3dmodels/TPL7407LDR.step
    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
    [TPL7407LDR.step]
2026-07-04 @ Wire solenoid driver + status LEDs + I2C cleanup; route + connect
    - Solenoid driver (U1 TPL7407): IN1-7 <- Teensy GPIO_1-7 (back-layer fanout,
    vias off the SMD pads), COM->+24V, GND->plane, OUT1-7 -> J5 screw terminal
    - Add 7 solenoid status LEDs (GPIO_1-7) + COM/+24V indicator LED (0402)
    - Remove LTC4311 I2C accelerators (U9/U10) - misbehaved on lightly-loaded
    buses (single-valve failure); kept passive pull-ups. Restored SCL2/SDA2
    pull-ups (R41/R42)
    - Back layer: full-board GND pour (clean rectangle outline)
    - Connect U1 GND and R4 (+24V power-indicator LED) to their nets
    DRC: unconnected down to 5, all intentional unused-pin no-connects
    (GPIO_8/9 + vestigial SPI). No shorts; vias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
    [bubblesensors.kicad_sch, fluidics-v2.kicad_pcb, fluidics-v2.kicad_sch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]
2026-07-04 @ Resize board to 94.25 x 106.25 mm; redraw front GND pour
    - Shrunk Edge.Cuts from ~127x127 to 94.25 x 106.25 mm (single Rect, closed)
    - All 85 footprints fit inside the new outline; all 5 zones re-poured
    (front/back GND, In1 GND plane, In2 +24V/+5V planes)
    - Redrew the front F.Cu GND zone (was deleted during resize)
    DRC: outline valid, no copper-to-edge or clearance errors, 5 unconnected
    (expected unused-pin no-connects). Remaining are cosmetic: silk-edge-clearance
    (20, silk now near the smaller edge) + inherited silk/courtyard/lib warnings.
    @
    [fluidics-v2.kicad_pcb]
2026-07-07 Trim board: remove D1/D5-D8/R1/R2/R6-R8/H1, add connector J6
    PCB + root schematic + solenoid_driver sheet edits (GUI-driven).
    Footprints 85 -> 75. Removed diodes D1/D5-D8, resistors R1/R2/R6-R8,
    mounting hole H1; added connector J6. Schematic/PCB in parity
    (kicad-cli drc: schematic_parity 0). Remaining DRC items are the
    inherited-from-upstream cosmetic set (silk_over_copper, malformed
    _courtyard, lib_footprint_mismatch) plus 5 intentional no-connects
    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
    [fluidics-v2.kicad_pcb, fluidics-v2.kicad_sch, solenoid_driver.kicad_sch]
2026-07-07 Place Cephla logo on F.SilkS (30%), add logo footprints; i2c sheet edit
    - Placed bitmap2component logo (ref G***) on front silkscreen, scaled
    to 30% of original -> 12.40 x 4.88 mm; footprints 75 -> 76.
    - Add logo source footprints: ImageCephlaCompanyPCB.kicad_mod (full)
    + _30pct (placed variant). Abandoned Attempt2/3 left untracked.
    - i2c.kicad_sch: non-component edit (wiring/label), saved from GUI.
    [fluidics-v2.kicad_pcb, fluidics-v2.kicad_sch, i2c.kicad_sch]
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2026-07-07 PCB fix: add R1 (svalves), clear dangling track; refresh schematic PDF
    - Add resistor R1 on svalves sheet, placed on board; footprints 76 -> 77.
    - Prior dangling J6 track resolved (DRC track_dangling now 0).
    - DRC: schematic_parity 0, 5 intentional no-connects, rest cosmetic
    (silk/courtyard/padstack inherited from upstream).
    - Regenerate fluidics-v3-schematic.pdf from current schematic.
    [fluidics-v2.kicad_pcb, svalves.kicad_sch]
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2026-07-07 Add V3 fabrication package (fab_outs_v3/)
    Generated from the current board (77 footprints, incl. R1 + F.SilkS logo):
    gerbers zip (4 copper + masks/pastes/silks + Edge.Cuts + drill), loose
    gerbers, positions.csv (CPL), bom.csv (34 groups), and fluidics-v3.step.
    fluidics-v3-gerbers.zip is the JLCPCB-ready upload.
    [bom.csv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]
2026-07-07 Rename project directory fluidics-v2 -> fluidics-v3
    Move the KiCad project folder to match the V3 naming (48 tracked files).
    Library tables use ${KIPRJMOD}/../ relative paths, so links are unaffected.
    Project files inside keep the fluidics-v2.kicad_* basename (dir name is
    independent of the KiCad project name). Update README path reference.
    [bubblesensors.kicad_sch, fluidics-v2.kicad_pcb, fluidics-v2.kicad_sch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]
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2026-07-07 Reorganize repo into clean top-level folders
    Tidy the project hierarchy without altering the KiCad design:
    - Rename "User KiCad Library" -> library; rewrite all 142 fp/sym-lib-table
    URIs (../User KiCad Library -> ../library). PCB/schematic reference libs
    by nickname only, so no design files changed. DRC unchanged (parity 0).
    - fab_outs -> fabrication/v2, fab_outs_v3 -> fabrication/v3.
    - Move docs to docs/: V3_CHANGES.md, PDFs, BOM csv, bom2grouped xsl.
    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
    [Fluidics Controller Complete BOM - Sheet1.csv, bom.csv, designators.csv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]
2026-07-07 Swap 2x terminal blocks MKDS-1,5-2-5.08 -> MPT-0,5-2-2.54
    Replace two 1x02 Phoenix terminal blocks with the smaller MPT series
    (2.54mm pitch, 5.54x6.20mm body vs 10.16x9.80mm) to reclaim board space.
    Schematic + PCB updated; DRC parity 0. Note: MPT rated for 0.5mm2 wire
    (vs 1.5mm2 on MKDS) - lower current/wire-gauge capacity.
    [fluidics-v2.kicad_pcb, solenoid_driver.kicad_sch]
2026-07-07 Regenerate fabrication/v3 + schematic PDF after terminal-block swap
    Rebuild gerbers/drill/positions/BOM/STEP and the rendered schematic to
    reflect the MKDS-1,5-2-5.08 -> MPT-0,5-2-2.54 change. fluidics-v3-gerbers.zip
    is the JLCPCB-ready upload.
    [bom.csv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]
2026-07-08 Add GPIO_5 status LED and +24V screw terminal J7
    - Root sheet: GPIO_5 status LED (D12 + R12 2.7K to GND)
    - Solenoid driver sheet: J7 2-pin screw terminal (pin2 = +24V)
    Schematic parses clean via kicad-cli; D12/R12/J7 present in netlist.
    [fluidics-v2.kicad_pcb, fluidics-v2.kicad_sch, solenoid_driver.kicad_sch]
2026-07-09 Regenerate v3 fab package after GPIO_5 LED + J7 (f6e9c47)
    Gerbers/drill/map, CPL positions, BOM, STEP, and schematic PDF rebuilt
    from the current board (DRC electrically clean: 0 clearance/shorting).
    Now reflect D12/R12 GPIO_5 status LED, J7 +24V terminal, and the
    J5->3x 1x02 terminal rework.
    Gerbers regenerated with --no-protel-ext to keep the prior .gbr naming.
    STEP still missing one 3D shape (MAX3221CPWR.stp / U11) - pre-existing
    library gap, not fab-critical.
    [bom.csv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]
2026-07-09 Consolidate solenoid outputs to single 1x06 terminal J5
    Replace 3x 1x02 blocks (J5/J6/J7) with one 6-position Xinya XY308-2.54-6P
    (J5): pads 1/3/5 = U1 TPL7407 OUT5/6/7, pads 2/4/6 = +24V. DRC electrically
    clean (0 clearance/shorting; 5 unconnected are intentional U2 GPIO/SPI NC).
    Assign 3D model: KiCad 10 ships no Xinya XY308 .step, so point J5's model at
    the bundled Phoenix MPT-0,5-6-2.54 1x06 (same pitch/positions) for the 3D
    preview. Footprint/BOM/CPL still reference the real Xinya part.
    [fluidics-v2.kicad_pcb, fluidics-v2.kicad_sch, solenoid_driver.kicad_sch]
2026-07-09 Regenerate v3 fab package for 1x06 J5 consolidation
    Gerbers/drill/map, CPL positions, BOM, STEP, schematic PDF rebuilt from the
    current board. STEP now includes J5 (via the MPT-6 stand-in model); only
    MAX3221CPWR.stp (U11) still missing - pre-existing library gap.
    [bom.csv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]
2026-07-13 v3 PCB: 3.3V power-plane islands + B.Cu bridge, refdes to F.Fab, block silk labels
    PCB (this session, verified DRC-clean, 0 electrical regressions):
    - Add +3.3V copper islands on In2.Cu (top U11/IC2 cluster + LDO/I2C-connector corner)
    - Add +3.3V bridge pour on B.Cu down the inter-island corridor; delete ~18mm redundant vertical run
    - Stitch 3.3V loads to islands with vias; remove ~35mm circuitous surface routing (3.3V trace 194->68mm)
    - Move 21 hidden reference designators (caps, R22/R23/R51, U2 Teensy) to F.Fab, centered
    - Add functional F.Silkscreen labels: Solenoid Driver, Flow, I2C Iso, RS-232
    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
    [fluidics-v2.kicad_pcb, fluidics-v2.kicad_sch, solenoid_driver.kicad_sch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]
2026-07-13 v3 PCB: complete +24V input-protection front-end + downsize bulk caps
    Input stage (J1 barrel jack -> TH1 NTC inrush limiter -> +24V plane):
    - Fix +24V-into-J1 short + solder-mask bridge (leftover rail track ran
    into the /+24V_IN pad after J1 was repurposed as the input)
    - Tie in U6.5 GND and C3 +24V bulk cap; stitch 3 isolated GND pour islands
    - Route /+24V_IN on Front at 1.5mm (carries full board +24V current)
    Bulk caps downsized, capacitance unchanged, all re-tied via-to-plane:
    - C3 100uF/+24V: electrolytic CP_Elec_8x10.5 -> polymer CP_EIA-7343-20 (~2mm)
    - C4 47uF/+3V3: electrolytic -> C_1206 ceramic
    - C10 100uF/+5V: electrolytic -> C_1210 ceramic
    Schematic footprints updated to mat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
    [fluidics-v2.kicad_pcb, fluidics-v2.kicad_sch]
2026-07-16 Regenerate v3 fab package + schematic PDF for input-stage & cap changes
    Refresh gerbers (.gbr), drill, drill map, BOM, positions, STEP, gerber zip,
    and the schematic PDF to match the current board (cc10f56):
    - +24V input-protection front-end: J1 barrel jack -> TH1 NTC -> +24V plane,
    /+24V_IN routed on front copper at 1.5 mm
    - bulk caps downsized: C3 100uF -> CP_EIA-7343-20 polymer, C4 47uF -> C_1206,
    C10 100uF -> C_1210 ceramic
    [bom.csv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]
2026-07-16 v3: mounting holes M2->M3, relink C3/C4/C10, regen fab package
    Mounting holes H2-H4: MountingHole_2.2mm_M2 -> 3.2mm_M3 (PCB + schematic,
    parity clean). Note: still 3 holes, no H1 (the original board had 4x M3).
    Fix bulk-cap schematic links. C3/C4/C10 had no (path) link to their
    symbols and lacked the library prefix in their footprint id, so "Update
    PCB from Schematic" deleted and re-added them (losing routing). Relinked:
    - C3 Capacitor_Tantalum_SMD:CP_EIA-7343-20_Kemet-V -> /cbfc97bd
    - C4 Capacitor_SMD:C_1206_3216Metric -> /5064b71f
    - C10 Capacitor_SMD:C_1210_3225Metric -> /25d2ffd2
    Regenerated fabrication/v3 (gerbers, drill incl. new 3.2mm tool, gerber
    zip, STE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
    [bom.csv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]
2026-07-16 v3: align mounting holes to shared X/Y + regen fab
    Snap M3 mounting holes onto shared orthogonal lines for manufacturing:
    - Left column H2, H4 -> X = 114 (H4 moved 115->114; H2 kept, since X=115
    overlaps C6 courtyard + the +24V zone)
    - Bottom row H4, H3 -> Y = 112 (H3 moved 111.697->112)
    Refilled all 8 copper zones so the +24V/+5V planes carve correctly
    around the relocated holes. Regenerated fabrication/v3 (gerbers, drill,
    gerber zip, STEP, positions) to match.
    DRC: 0 clearance/hole/courtyard/short/isolated, 0 schematic-parity.
    Remaining pre-existing: 24 malformed_courtyard on U2, 6 unconnected
    (5 intentional U2 no-connects + 1 +5V stub).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
    [fluidics-v2-B_Mask.gbr, fluidics-v2-B_Paste.gbr, fluidics-v2-B_Silkscreen.gbr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]
2026-08-06 Split Teensy U2 into module + two 1x24 SMT sockets
    U2 was one part standing in for three physical items: the Teensy 4.1 module
    and the two 24-pin SMT socket strips it plugs into. The sockets existed only
    as 3D models -- no refdes, no BOM line, no CPL entry -- so an assembler had
    no way to order or place them.
    New footprint teensy4.1:PinSocket_1x24_P2.54mm_Vertical_SMD_DualLand: 48 pads,
    pin numbers 1-24 doubled, coordinates lifted verbatim from U2's lands. Every
    pin has a land on both sides (the union of the Harwin M20-786 pin1-left and
    pin1-right tail patterns), so strips fit in either orientation and a row may
    be made up from shorter pieces. One footprint serves both sockets -- J7 is J6
    r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
    [bom.csv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]
2026-08-06 DNP the orphaned LTC4311, clean the CPL, fix undersized silk text
    U6 (LTC4311 I2C accelerator) and R1 (0R) are vestigial from the accelerator
    removal and cannot work as placed: pcbnew connectivity shows U6.1/U6.3 are the
    only two of the twenty +5V pads unreachable from the buck output U4.5, and the
    bus pins connect solely to each other -- Net-(U6-BUS1) = {U6.6, R1.1},
    Net-(U6-BUS2) = {U6.4, R1.2}. Marked DNP on both the schematic (svalves sheet)
    and the board rather than deleted, so the copper is left untouched and the
    choice is reversible; deleting both is the cleaner fix for a future revision.
    H2/H3/H4 (mounting holes) and TP1/TP2/TP3 (test points) are not placeable
    parts but were being e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
    [bom.csv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]
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2026-08-22 U3: swap AP7366EA-33W5-7 -> AP2112K-3.3TRG1
    Pin-compatible drop-in for the +3.3V LDO. Both parts are 600mA CMOS
    LDOs with enable in SOT-23-5, and the fixed-output pin assignment is
    identical (1=IN, 2=GND, 3=EN, 4=NC, 5=OUT), matching the board wiring
    (+5V / GND / +5V / no-connect / +3.3V). Footprint unchanged
    (Package_TO_SOT_SMD:SOT-23-5), so no layout impact.
    Schematic, PCB and both BOMs updated together; schematic parity 0,
    DRC 0 errors. Value text is on F.Fab only, so the existing gerbers and
    positions.csv remain valid and were not regenerated.
    Note: order the FIXED 3.3V variant. On the ADJ version pin 4 is the
    feedback pin, not a no-connect.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
    [Fluidics Controller Complete BOM - Sheet1.csv, bom.csv, fluidics-v2.kicad_pcb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]
2026-08-25 U4: replace Pololu D24V10FX with Traco TSR1-2450E, drop 5V power-good
    Swap the 24V->5V step-down for a Traco TSR 1-2450E (SIP-3, through-hole,
    1A) using the stock KiCad symbol/footprint pair. The TSR is a 3-pin part,
    so the Pololu's PG and nSHDN pins go away; nSHDN was already unconnected.
    Schematic:
    - psu: U4 -> Converter_DCDC:TSR1-2450E on
    Converter_DCDC:Converter_DCDC_TRACO_TSR1-xxxxE_THT
    - Remove the PG-5V hierarchical label, sheet pin, wire stub and the 47k
    pull-up R51; PG-5V no longer exists as a net
    - No-connect flags on J7 pin 1 and U2 pin 25, freeing Teensy pin 33
    PCB:
    - Place U4 at (156.437, 71.905) rot +90 so Vin lands on the existing +24V
    arrival node; GND and Vout follow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
    [fluidics-v2.kicad_pcb, fluidics-v2.kicad_sch, psu.kicad_sch]
2026-08-26 v3: finish TSR regulator swap, reconcile BOM, regenerate fab outputs
    Follow-up to a773dae, which replaced the Pololu D24V10FX with a Traco
    TSR 1-2450E. Completes the board cleanup and brings the fabrication
    package back in step with the design.
    Board:
    - Remove the redundant B.Cu 3.3V spine at x=152.62; the 3V3_bridge_Bcu
    zone already carried that path, so connectivity is unchanged
    - Move the "24V->5V Module" silk label clear of U4's outline
    - R10 42K -> 47K. 42k is not an E24 value; R4 already uses 47k on the
    same +24V rail feeding an identical indicator LED, and the current
    difference is 0.52mA vs 0.47mA
    DRC 0 errors, schematic parity clean, 6 unconnected items (all
    pre-existing). C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
    [bom.csv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]
2026-09-09 v3: +24V soft-start front end, U1 COM bypass, silkscreen and BOM fixes
    Power input stage
    - Replace TH1 (10 ohm NTC) with a low-side N-channel soft-start: Q1 (F60N80,
    TO-220) with a 100k/68k gate divider (R2/R6) and 0.1u timing cap (C11).
    The NTC sat in series with the whole board and dissipated 1.5-10 W; at
    1.85 A it was already over a 7 mm disc's rating before any valve moved.
    - Split ground: /GND1 (J1 shell + pin 2) is now separate from GND, with Q1
    bridging them. Removed a leftover 2.39 mm GND track that still touched
    J1.S2 and shorted straight across Q1.
    - Add C12 470u/50V bulk and C13 0.1u HF bypass on +24V. C3 alone left the
    300 kHz - 100 MHz band uncovered while U4 switche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
    [bubblesensors.kicad_sch, fluidics-v2.kicad_pcb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]
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2026-09-09 fab: mark J6/J7 DNP - Teensy sockets are hand-fitted
    J6 and J7 (SSM-124-L-SV) are sourced and soldered in-house, so the board
    house should not fit them. Set dnp on both the symbols and the footprints
    rather than "exclude from BOM", because DNP states the intent - the parts
    belong on the board, the assembler just skips them - and both exporters
    honour --exclude-dnp, which keeps the two files in step automatically.
    Regenerated with --exclude-dnp on both sides:
    - BOM 34 rows, 76 designators
    - CPL 76 designators
    - reconciled: nothing on one side only, no reference ranges
    All 12 through-hole parts stay in (C12, J1, J3, J5, J11, J13, J16, J19,
    J22, J24, Q1, U4) since THT assembly is being orde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
    [fluidics-v3-bom.csv, fluidics-v3.kicad_pcb, fluidics-v3.kicad_sch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]
2026-09-09 J3: open D-Sub mounting holes to 3.20 mm
    The Connfly DS1037 datasheet (JLCPCB C77837, DS1037-15MNCKT74-0CC) gives a
    recommended PCB layout of Ø3.20 for the shell mounting holes; the footprint
    had 3.05. Everything else already agreed:
    mounting hole separation 33.32 spec vs 33.300 on board
    pin pitch 2.77 vs 2.770
    row spacing 2.84 vs 2.840
    pin hole Ø1.00 vs 1.00
    rows 8 + 7 standard density, right angle
    The B=33.32 figure for 15 positions confirms standard density (DA-15) rather
    than HD-15, which is the failure mode worth ruling out on a "15-pin D-Sub".
    Ø3.20 is the normal #4-40 clearanc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
    [fluidics-v3-B_Mask.gbr, fluidics-v3-B_Paste.gbr, fluidics-v3-B_Silkscreen.gbr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]
2026-09-10 fab: apply JLCPCB part selections to BOM, annotate strays, normalise CPL
    Sourcing
    - Write Manufacturer_Part_Number / Manufacturer_Name / LCSC for every part
    from the JLCPCB BOM-matching sheet. 33 of 34 BOM rows now carry an LCSC
    code; the exception is J10/J12/J14/J18/J21/J25 (Molex 87832-0410), which
    JLCPCB returned "No matches" for and still needs a part chosen.
    Substitutions accepted from the sheet
    - IC2 ADuM1250WSRZ-RL7 -> ISO1640BDR (TI). Verified pin-for-pin against the
    board: 1 VCC1, 2 SDA1, 3 SCL1, 4 GND1, 5 GND2, 6 SCL2, 7 SDA2, 8 VCC2.
    - C3 -> KEMET T521X336M050ATE050, which is 33uF/50V, not 100uF. Value
    updated to match. The 50 V rating fixes the derating problem the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
    [bubblesensors.kicad_sch, fluidics-v3-bom.csv, fluidics-v3.kicad_sch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]

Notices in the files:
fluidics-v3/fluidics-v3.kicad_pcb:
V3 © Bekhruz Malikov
